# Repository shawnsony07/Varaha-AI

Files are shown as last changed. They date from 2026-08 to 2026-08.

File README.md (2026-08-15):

# Varaha AI: Autonomous Wild Boar Deterrent & Long-Range Telemetry Swarm 🐗📡

<p align="center">
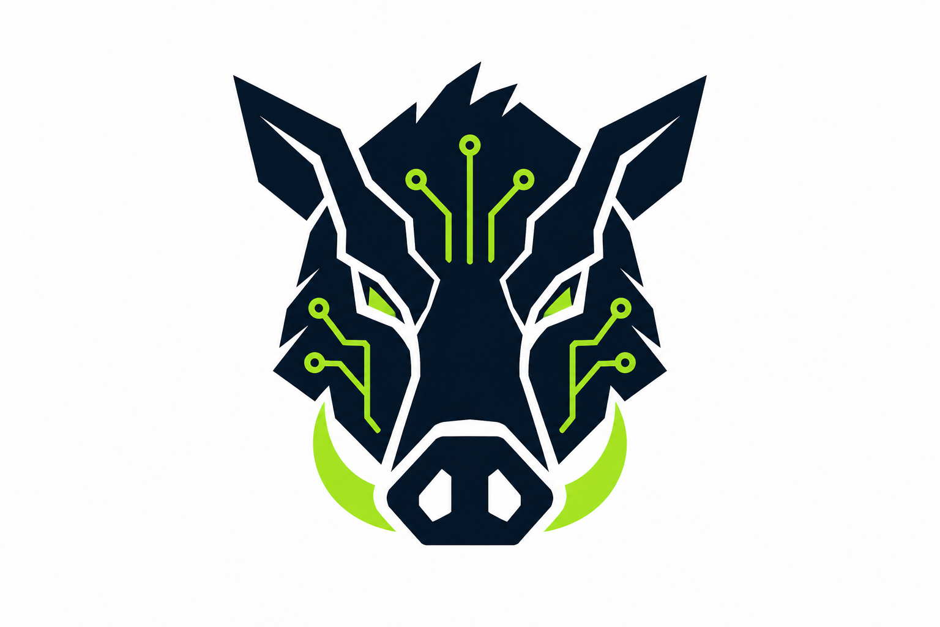
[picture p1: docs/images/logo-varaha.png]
Varaha AI Logo
  
</p>






**Repository Link:** https://github.com/shawnsony07/Varaha-AI

**Demonstration Video:** [Watch on YouTube](https://youtu.be/mFBCUHmKaQ8) 
> [!NOTE]
> The frequency has been shifted into the audible range for this demo so you can hear it working!
---

## 📖 Table of Contents
1. [Project Overview](#-project-overview)
2. [Inspiration & Problem Statement](#-inspiration--problem-statement)
3. [Functionality & Output](#-functionality--output)
4. [The Optimization Journey (Arm-Specific Acceleration)](#-the-optimization-journey-arm-specific-acceleration)
5. [Hardware Architecture](#%EF%B8%8F-hardware-architecture)
6. [Repository Structure](#-repository-structure)
7. [Setup Instructions](#-setup-instructions)
8. [License](#-license)

---

## 💡 Project Overview

**Varaha AI** is an intelligent, dual-node agricultural protection system combining on-device Swift-YOLO vision models, 35 kHz analog ultrasonic deterrence, and P2P LoRa telemetry.

**Why 35 kHz Ultrasonic Deterrence?**
While human hearing typically tops out around 20 kHz, wild boars possess a significantly higher auditory range. When the vision model detects a threat, it triggers a targeted 35 kHz ultrasonic sweep. This causes acute auditory discomfort that drives the boars away from crops, while remaining completely silent and harmless to farmers and local residents.

> [!IMPORTANT]
> **🏆 Why Varaha AI should win:**
> Most existing wildlife deterrent solutions are blunt instruments — electric fences that shock anyone who touches them, poison bait that enters the food chain, or loud acoustic sirens that disturb entire communities through the night. Varaha AI is fundamentally different: it is a **targeted, non-lethal, and human-safe** solution. The 35 kHz ultrasonic deterrent is completely inaudible to humans, causes no harm to livestock or birdlife, and leaves zero environmental footprint. It only activates when the Arm-accelerated vision model confirms a boar is present — not a farmer, not an animal, not a false alarm.
>
> Beyond its ethical design, Varaha AI is not a software-only optimization — it is a complete, field-deployable AI system that closes the loop from raw pixel inference to physical deterrence hardware. We achieved **100% NPU offload** on the Arm Ethos-U55 with **zero CPU fallbacks**, running a production Swift-YOLO model in just **198 KiB of SRAM** — an extreme memory constraint that required the full Arm Vela compilation pipeline. This tight integration of Arm-accelerated TinyML inference with custom analog electronics, off-grid LoRa telemetry, and a 3D-printed weatherproof enclosure demonstrates what Arm-powered edge AI can do in the real world: protect livelihoods, eliminate cloud dependency, and run indefinitely on a battery in a field.

<p align="center">
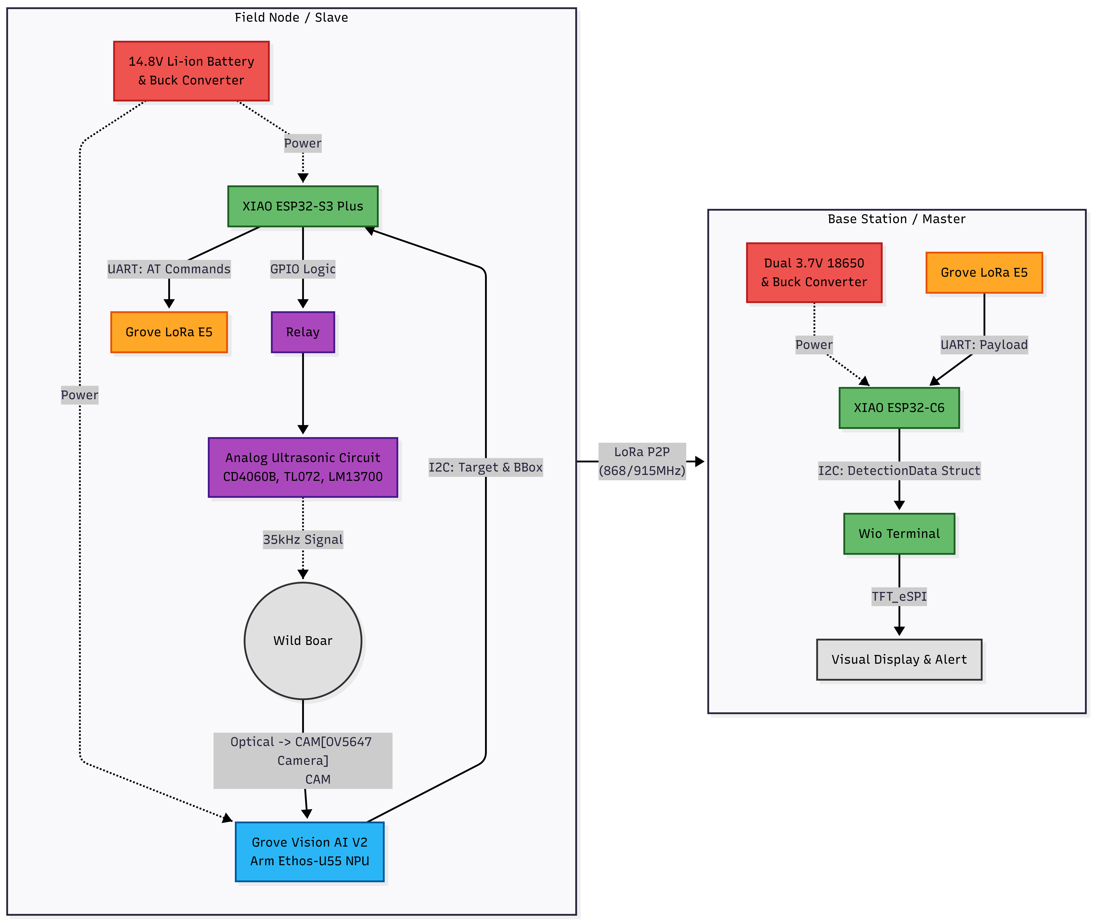
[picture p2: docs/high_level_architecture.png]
High Level Architecture
  
  <br><i>Figure 1: High Level Architecture of the Varaha AI System</i>
</p>

---

## 🌍 Inspiration & Problem Statement

Human-wildlife conflict—specifically destructive foraging by wild boars—causes severe agricultural losses for farming communities worldwide, with the crisis reaching a breaking point in Kerala, India. Kerala's wild boar population grew by more than **40%** over 15 years, reaching approximately 58,000 in 2019. These highly adaptable animals breed quickly and feed indiscriminately, heavily damaging essential local crops like tapioca, sweet potatoes, and plantains.

Beyond economic devastation—where some farmers report daily losses up to **Rs 150** and suffer through a broken compensation system—the boars pose a severe physical threat. Wild boars are responsible for sudden, unprovoked attacks and human fatalities occurring entirely outside of forested areas. Traditional solutions like electric fencing are expensive to install and maintain across vast acreage, while manual patrols are hazardous and unsustainable.

Varaha AI was engineered to solve this crisis by providing a completely autonomous, field-deployable shield. By coupling hardware-accelerated computer vision at the far edge with targeted ultrasonic harassment and long-range radio alerts, farmers get real-time crop protection without relying on cellular infrastructure or cloud connectivity.

---

## ⚡ Functionality & Output

Varaha AI operates as a fully autonomous detection-to-deterrence pipeline. Here is the complete end-to-end flow triggered by a single boar detection event:

```mermaid
flowchart TD
    classDef camera    fill:#FFD700,stroke:#333,stroke-width:2px,color:#000
    classDef npu       fill:#00C853,stroke:#333,stroke-width:2px,color:#000
    classDef model     fill:#69F0AE,stroke:#333,stroke-width:2px,color:#000
    classDef logic     fill:#40C4FF,stroke:#333,stroke-width:2px,color:#000
    classDef deterrent fill:#FF6D00,stroke:#333,stroke-width:2px,color:#000
    classDef lora      fill:#E040FB,stroke:#333,stroke-width:2px,color:#000
    classDef base      fill:#FF4081,stroke:#333,stroke-width:2px,color:#000
    classDef display   fill:#18FFFF,stroke:#333,stroke-width:2px,color:#000

    CAM["📷 OV5647 Camera\nField Node"]:::camera
    VIS["🧠 Grove Vision AI V2\nWiseEye2 HX6538\nArm Cortex-M55 + Ethos-U55 NPU"]:::npu
    MDL["⚡ Swift-YOLO INT8\nmodel_vela.tflite\n100% NPU Offload\nBounding Box + Confidence Score"]:::model
    S3["🎛️ XIAO ESP32-S3 Plus\nLogic Controller"]:::logic
    DET["🔊 Analog Ultrasonic Circuit\n35 kHz Sweep\nCD4060B -> TL072 -> LM13700\n-> MOSFET -> Piezo Transducer"]:::deterrent
    LORA["📡 Grove Wio-E5\nLoRa P2P | 866 MHz\nSF12 | BW125 | 14 dBm"]:::lora
    C6["📻 XIAO ESP32-C6\nBase Station\nDecodes: Flag | RSSI | SNR"]:::base
    WIO["🖥️ Wio Terminal\nTFT UI Dashboard\nLive Alerts · Signal Strength · Network Status"]:::display

    CAM -->|"Video Feed"| VIS
    VIS -->|"Runs inference"| MDL
    MDL -->|"I2C — Detection Result"| S3
    S3 -->|"Triggers 14.8V Relay"| DET
    S3 -->|"UART — LoRa Packet"| LORA
    LORA -->|"P2P Radio | up to several km"| C6
    C6 -->|"I2C"| WIO
```

**Final Output:** A boar is detected, silently repelled via targeted 35 kHz ultrasound (inaudible and harmless to humans), and the farmer receives an instant visual alert on a dashboard up to several kilometres away — all with zero cloud connectivity and zero CPU fallbacks on the Arm Ethos-U55 NPU.

---

## 🚀 The Optimization Journey (Arm-Specific Acceleration)

To meet the rigorous latency, memory, and power constraints of edge deployment, we conducted a three-tier model optimization process. Our goal was to maximize **Arm-specific optimization**, **model compactness**, and **inference speed** for the Grove Vision AI V2 (Arm Cortex-M55 + Ethos-U55).

<p align="center">
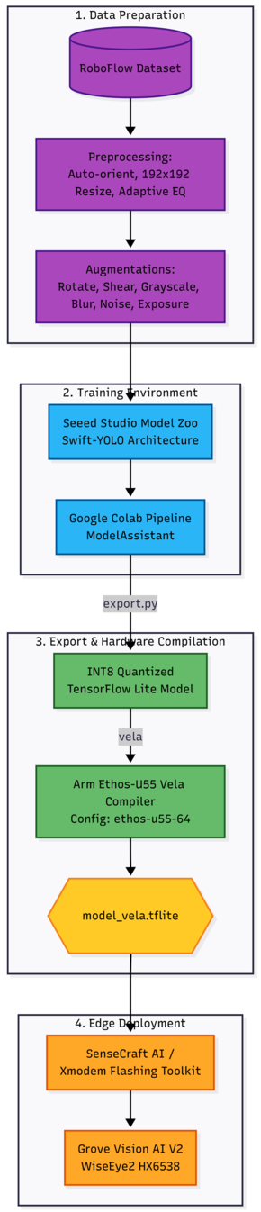
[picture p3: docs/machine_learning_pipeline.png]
Machine Learning Pipeline
  
  <br><i>Figure 2: Three-tier Machine Learning Optimization Pipeline</i>
</p>

### 📊 Comprehensive 3-Model Benchmark Comparison

| Metric / Parameter | Model 1: Edge Impulse FOMO | Model 2: Edge Impulse YOLO | Model 3: Swift-YOLO (SSCMA — Production) |
| :--- | :--- | :--- | :--- |
| **Pipeline / Framework** | Edge Impulse | Edge Impulse | Google Colab / SSCMA (ModelAssistant) |
| **Detection Task Type** | Centroid / Point Detection | Bounding Box Detection | Bounding Box Detection |
| **Input Resolution** | 96 × 96 | 160 × 160 | **192 × 192** |
| **Quantization Precision** | INT8 | INT8 | **INT8** |
| **Model Size on Disk/Flash** | **30.00 KiB** | **608.00 KiB** | **1024.70 KiB (1.00 MB)** |
| **mAP@50 (IoU=0.50)** | N/A *(Centroid Model)* | 77.4% | **70.2%** |
| **mAP@50:95 (Overall mAP)** | N/A *(Centroid Model)* | 41.9% | **37.7%** |
| **Precision** | 45.3% | ~51.6% | **68.4%** |
| **Recall (Overall)** | 14.1% | 49.4% | **54.9%** |
| **F1-Score** | 21.5% | ~50.5% | **60.9%** |
| **NPU Offload Rate** | Unverified (Partial CPU) | Unverified (Partial CPU) | **100.0% (175 / 175 Operators)** |
| **CPU Fallback Rate** | High | Moderate | **0.0% (0 Operators)** |
| **SRAM Footprint** | Unknown | Unknown | **198.00 KiB** |
| **Compute Workload** | ~30 M MACs | ~90 M MACs | **123.6 M MACs / inference** |
| **Target Arm Hardware** | Arm Ethos-U55 / Cortex-M55 | Arm Ethos-U55 / Cortex-M55 | **Arm Ethos-U55 NPU (500 MHz, 64 MACs/cycle)** |

---

### Model 1: Edge Impulse FOMO (The Baseline Prototype)
We initially tested a Faster Objects, More Objects (FOMO) centroid-detection architecture for its extreme speed.

| Parameter | Value |
| :--- | :--- |
| Architecture | FOMO (Centroid Detection) |
| Precision | 45.3% |
| Recall | 14.1% |
| F1-Score | 21.5% |
| Bounding Box Output | ❌ No |
| NPU Optimized | ❌ No |

> **Conclusion:** FOMO failed to capture the spatial context and varied postures of wild boars in dynamic outdoor environments. The critically low recall made it unviable for field protection.

---

### Model 2: Edge Impulse YOLO (The Accuracy Benchmark)
We escalated to a standard Bounding Box YOLO model to establish a target accuracy ceiling.

| Parameter | Value |
| :--- | :--- |
| Architecture | Bounding Box YOLO |
| mAP@50 | 77.4% |
| Overall mAP | 41.9% |
| Recall | 49.4% |
| Bounding Box Output | ✅ Yes |
| NPU Optimized | ❌ Partial (CPU fallbacks) |

> **Conclusion:** While highly accurate, standard YOLO ops frequently result in partial CPU fallbacks when deployed to micro-NPUs, creating latency bottlenecks and increased power draw.

---

### Model 3: Swift-YOLO via SSCMA (The Final Optimized Build) ✅
Our final iteration utilized a custom **Swift-YOLO** architecture trained via Seeed Studio ModelAssistant (SSCMA), INT8-quantized and compiled for the **Arm Ethos-U55 NPU** using the Vela toolchain.

| Parameter | Value |
| :--- | :--- |
| Architecture | Swift-YOLO (INT8 Quantized) |
| Training Framework | SSCMA (Seeed Studio ModelAssistant) |
| Compiler | Arm Vela |
| Target Hardware | Grove Vision AI V2 (WiseEye2 HX6538) |
| Target NPU | Arm Ethos-U55 |
| mAP@50 | **70.2%** |
| Recall | **54.9%** |
| SRAM Footprint | **198.00 KiB** |
| Off-Chip Flash Footprint | **1024.70 KiB** |
| Compute Workload | **123.6 M MACs / inference** |
| Total Operators | 175 |
| NPU Offload Rate | **100.0% (175 / 175 operators)** |
| CPU Fallback Rate | **0.0% (0 operators)** |
| Quantization | INT8 |
| Vela Compiled | ✅ Yes |

**The Optimization Victory:** We successfully traded a marginal 7.2% drop in mAP@50 to achieve a **100% Arm NPU execution rate**. By eliminating all CPU fallbacks and shrinking the active memory footprint to under 200 KiB of SRAM, Varaha AI achieves maximum FPS and drastically lower power consumption for continuous battery-operated field deployment.

<p align="center">
  Swift-YOLO Wild Boar Detection
  <br><i>Figure 3: On-device bounding box detection via Swift-YOLO</i>
</p>

---

## ⚙️ Hardware Architecture

Varaha AI operates on a seamless dual-node architecture.

<p align="center">
  Varaha AI Final Hardware Setup
  <br><i>Figure 4: The fully assembled Varaha AI Field Node and Base Station</i>
</p>

### 1. Field Node (Slave)
The Field Node acts as the silent watcher. An OV5647 camera feeds live video into the **Grove Vision AI V2**. A **XIAO ESP32-S3 Plus** acts as the logic controller, querying the vision module via I2C and transmitting LoRa packets via UART to a **Grove Wio-E5** (AT test mode, raw P2P — not LoRaWAN).

**LoRa RF Configuration (TX):**

| Parameter | Value |
| :--- | :--- |
| Frequency | **866 MHz** |
| Spreading Factor | **SF12** |
| Bandwidth | **125 kHz** |
| TX Power | **14 dBm** |
| Preamble Length | 12 |
| Protocol | Raw P2P Packet (`AT+TEST=TXLRPKT`) |
| Payload | Detection flag (`SEEED` + `01`/`00`) |

<p align="center">
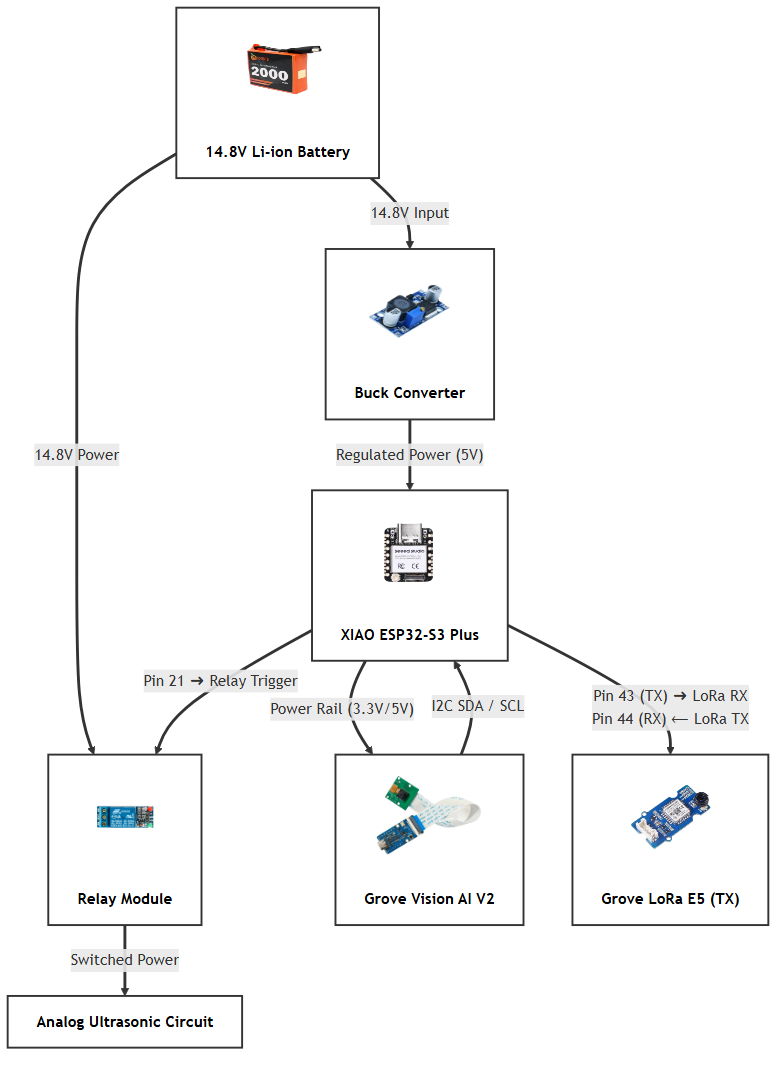
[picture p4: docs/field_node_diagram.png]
Field Node Wiring Diagram
  
  <br><i>Figure 5: Field Node (Slave) Wiring Diagram</i>
</p>

#### ⚡ Custom Analog Ultrasonic Deterrent Circuit
When a boar is detected, the S3 triggers a 14.8V relay. This powers a custom-engineered analog circuit featuring a **4.48 MHz crystal oscillator** and **CD4060B** binary counter/divider to generate a precise base frequency. The signal is buffered via a **TL072 op-amp**, shaped by an **LM13700 OTA**, and driven through a power MOSFET and 100 µH boost inductor into a piezoelectric transducer, blasting a 35 kHz sweep.

| Schematic Blueprint | Physical Prototype |
| :---: | :---: |
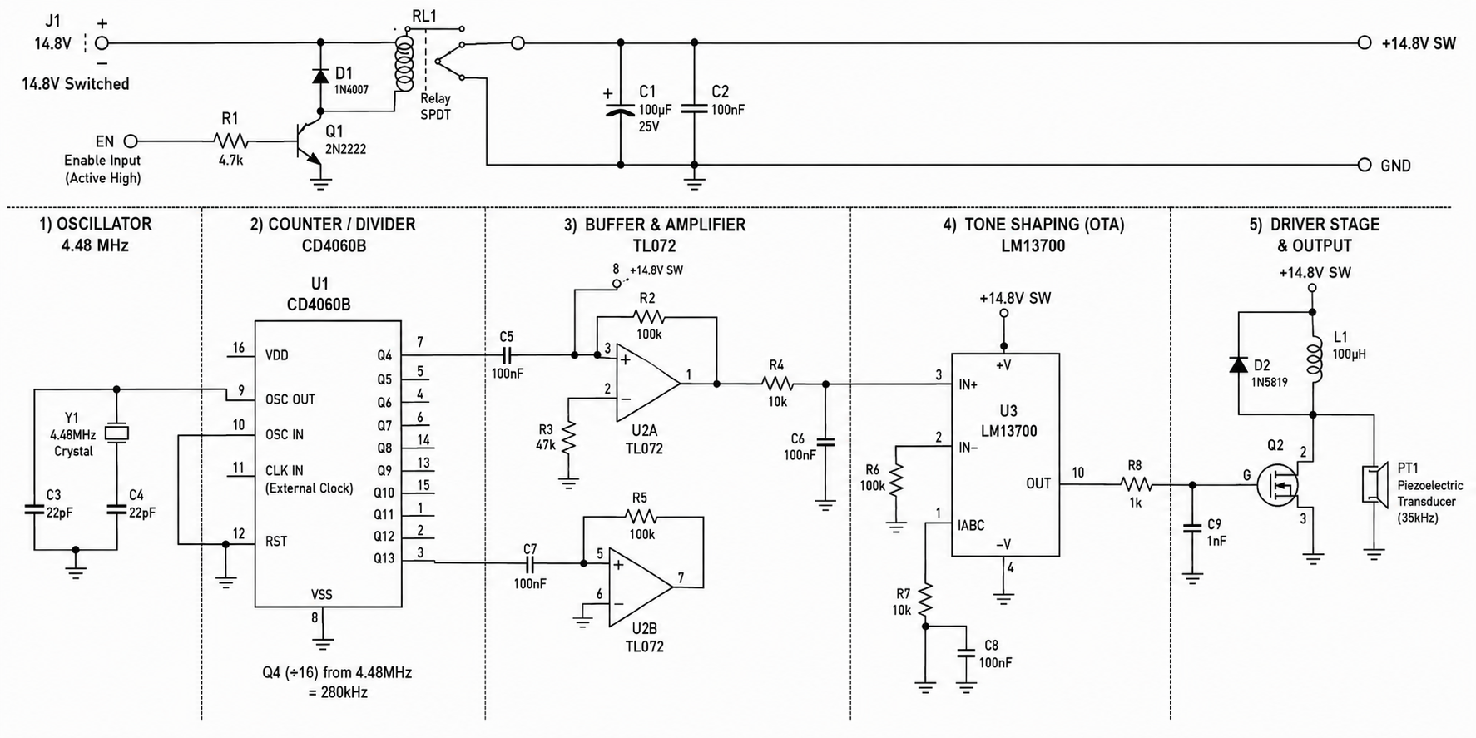
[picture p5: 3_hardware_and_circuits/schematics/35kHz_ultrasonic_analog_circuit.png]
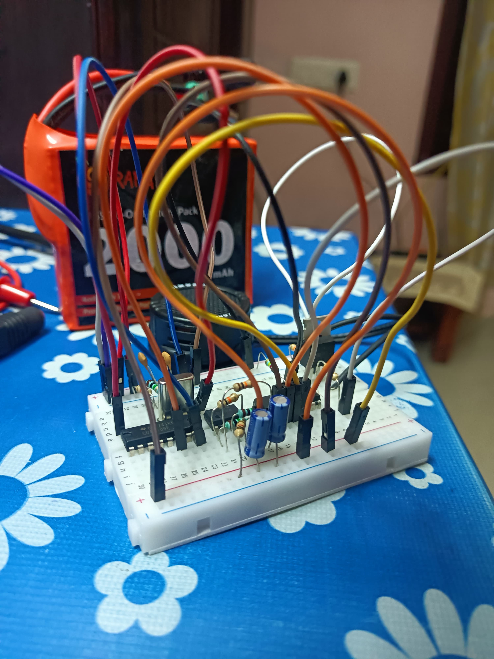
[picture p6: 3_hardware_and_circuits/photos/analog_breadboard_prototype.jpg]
|  |  |

#### 🛡️ Weather-Resistant 3D Enclosure
The node is housed in a custom-designed, 3D-printable enclosure (`HogWatch_Case_v2.stl`) featuring a recessed optical viewport, passive ventilation grids for the power step-down (buck converter), an acoustic port for the ultrasonic transducer, and a precise top slit that allows the lid to seamlessly slide in and out for easy internal access.

<p align="center">
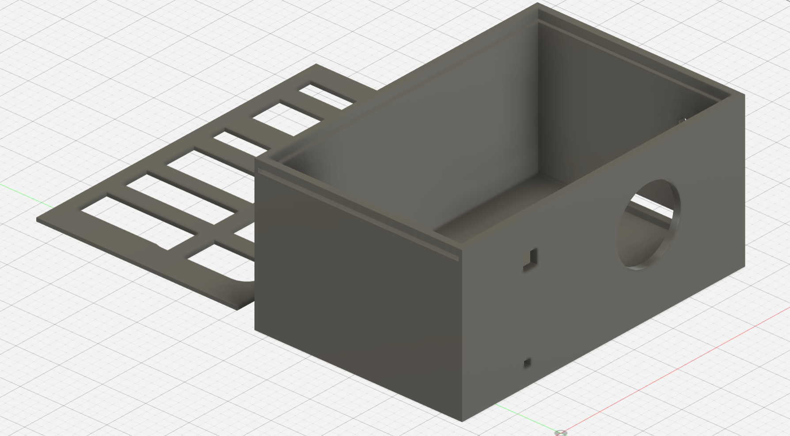
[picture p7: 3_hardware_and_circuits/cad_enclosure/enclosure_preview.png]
  
  <br><i>Figure 6: 3D-printable Weather-Resistant Enclosure</i>
</p>

### 2. Base Station (Master)
Located at the farmhouse, a **XIAO ESP32-C6** listens for P2P radio transmissions on **866 MHz** using a second Wio-E5 configured identically (`AT+TEST=RFCFG,866,SF12,125,12,15,14`). On packet reception, it decodes the telemetry (Detection Flag, RSSI, SNR) and pushes it via I2C to a **Wio Terminal**, rendering a color TFT UI Dashboard with live alerts and network diagnostics.

<p align="center">
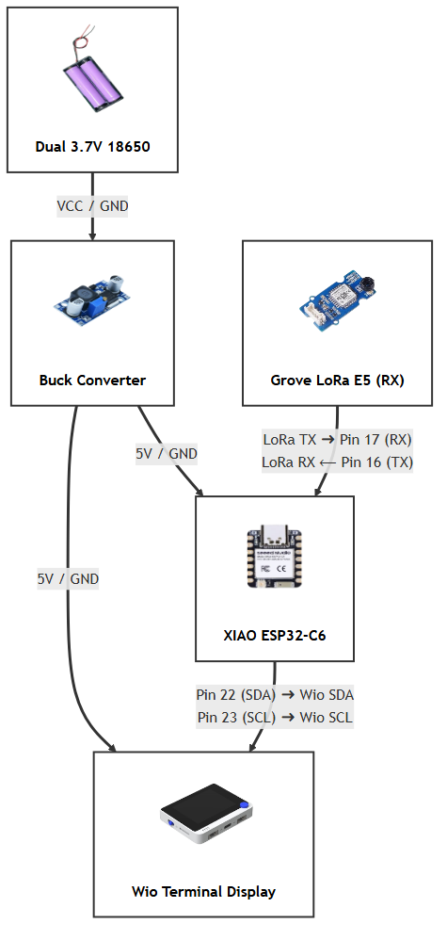
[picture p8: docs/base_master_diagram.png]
Base Master Diagram
  
  <br><i>Figure 7: Base Station (Master) Wiring Diagram</i>
</p>

---

## 📂 Repository Structure

```text
Varaha-AI/
├── 1_machine_learning_pipeline/         # Model evaluation and training progression
│   ├── model_1_edge_impulse_fomo/       # Tier 1: Initial Centroid Detection Prototype
│   ├── model_2_edge_impulse_yolo/       # Tier 2: Standard Bounding Box Model
│   └── model_3_swift_yolo_sscma/        # Tier 3: Production Hardware-Optimized Model
│       ├── notebooks/                   # Swift-YOLO Colab training pipeline
│       └── compiled_artifacts/          # INT8 Vela compiled binaries (model_vela.tflite)
│
├── 2_edge_node_firmware/                # Embedded C++ codebase
│   ├── field_slave_node_s3/             # XIAO ESP32-S3 + Vision AI + LoRa TX + Relay
│   ├── base_master_node_c6/             # XIAO ESP32-C6 + LoRa RX
│   └── wio_terminal_display/            # Wio Terminal I2C Slave + TFT UI Dashboard
│
├── 3_hardware_and_circuits/             # Schematics, prototypes, and CAD
│   ├── cad_enclosure/                   # 3D printable STL files
│   ├── photos/                          # Prototype implementation photos
│   └── schematics/                      # Analog circuit & power distribution diagrams
│
├── tools/xmodem_flasher/                # Python scripts for flashing Grove Vision AI V2
└── docs/                                # Visual assets for architecture & wiring
```

---

## 🛠️ Setup Instructions

### Prerequisites — Arduino Libraries
Install the following libraries via the Arduino IDE Library Manager before compiling:

| Library | Board Target |
| :--- | :--- |
| `Seeed Arduino SSCMA` | XIAO ESP32-S3 (Vision AI I2C) |
| `Seeed_Arduino_LoRaWan` | XIAO ESP32-S3 & C6 (Wio-E5 UART) |
| `Seeed Arduino rpcWiFi` | Wio Terminal |
| `Seeed Arduino FS` | Wio Terminal |
| `Seeed Arduino SFUD` | Wio Terminal |
| `TFT_eSPI` | Wio Terminal (TFT Display) |

Board package URLs to add in Arduino IDE → Preferences:
`https://files.seeedstudio.com/arduino/package_seeeduino_boards_index.json`

---

### 1. Build and Flash the ESP32 & Wio Terminal Nodes
1. Wire your hardware components according to the Pictorial Wiring Diagrams (Figures 3 and 5).
2. Open the Arduino IDE.
3. Navigate to `2_edge_node_firmware/` and open the respective `.ino` files.
4. Select your target boards from the Boards Manager:

| File | Target Board |
| :--- | :--- |
| `field_slave_node_s3/HogWatch-lora-vision.ino` | XIAO ESP32-S3 |
| `base_master_node_c6/HogWatch_esp32_c6_wio_terminal.ino` | XIAO ESP32-C6 |
| `wio_terminal_display/HogWatch_wio_terminal.ino` | Seeed Wio Terminal |

5. Compile and upload the code to each respective microcontroller.

---

### 2. Deploy the Optimized Model to the Arm Ethos-U55
The highly-optimized NPU model must be flashed to the Grove Vision AI V2 (WiseEye2 HX6538) via the XMODEM protocol using the provided Python toolset.

1. Connect the Grove Vision AI V2 to your computer via USB-C.
2. Install the flashing dependencies:
```bash
pip install -r tools/xmodem_flasher/requirements.txt
```

3. Run the XMODEM flashing script to deploy the `model_vela.tflite` payload:

```bash
python3 tools/xmodem_flasher/xmodem_send.py --port=COM_PORT --baudrate=921600 --protocol=xmodem --file=firmware.img --model="1_machine_learning_pipeline/model_3_swift_yolo_sscma/compiled_artifacts/model_vela.tflite 0x200000 0x00000"
```

*(Replace `COM_PORT` with your Serial Port, e.g., `COM3` on Windows or `/dev/ttyUSB0` on Linux/macOS)*

---

### 3. Run & Validate on the Physical Arm-Powered Device

Once the model is flashed to the Grove Vision AI V2, you can validate the NPU inference and the full hardware pipeline:

1. **Power the System:** Power on the Base Station (XIAO ESP32-C6) and the Field Node (Grove Vision AI V2 + XIAO ESP32-S3).
2. **Monitor the Edge Node:** Connect the Field Node's XIAO ESP32-S3 to your computer and open a Serial Monitor at `115200` baud.
3. **Trigger a Detection:** Point the Grove Vision AI V2 camera at a wild boar (or a monitor displaying an image/video of a wild boar).
4. **Validate NPU Output:** In the Serial Monitor, confirm the I2C payload transfer from the Arm Cortex-M55/Ethos-U55:
```text
Vision: Wild boar detected! Score=82, Box=[x,y,w,h]
LoRa TX: Wild boar DETECTED
```

5. **Validate Hardware Deterrent:** Listen for the physical "click" of the 14.8V relay activating the analog ultrasonic deterrent circuit.
6. **Validate LoRa Telemetry:** Look at the Wio Terminal screen. The UI will instantly shift from a green **"FIELD CLEAR"** status to a flashing red **"BOAR DETECTED!"** alert.

---

### 4. Validate Inference via Arm Virtual Hardware (AVH) / CLI

To validate that the Vela-compiled model runs correctly on an Arm Cortex-M55 + Ethos-U55 target *without* physical hardware, use the Ethos-U NPU driver simulator:

```bash
# Install Arm's ethos-u-vela toolchain
pip install ethos-u-vela

# Inspect operator offload summary of the compiled model
vela 1_machine_learning_pipeline/model_3_swift_yolo_sscma/compiled_artifacts/model_vela.tflite \
     --accelerator-config=ethos-u55-64 \
     --system-config=Ethos_U55_High_End_Embedded \
     --output-dir=./vela_validation_output

# Review output — confirm 175/175 operators on NPU, 0 on CPU
cat vela_validation_output/epoch_100_int8_summary_Ethos_U55_High_End_Embedded.csv
```

---

## 📜 License
This project is open-source and released under the MIT License. See the [LICENSE](LICENSE) file for complete details.

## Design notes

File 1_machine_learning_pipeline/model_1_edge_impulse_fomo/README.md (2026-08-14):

# Model 1 — Edge Impulse FOMO (Tier 1 Baseline)

## Architecture
Faster Objects More Objects (FOMO) — a lightweight centroid-detection model designed for microcontrollers. Trained via Edge Impulse on the Varaha hog dataset.

## Purpose
Initial prototype to validate the feasibility of on-device pig detection. FOMO outputs object centroids rather than bounding boxes, making it extremely fast but less precise.

## Key Results
See model.4_fomo_8.json for evaluation metrics and confusion matrix output.

## Limitations
- No bounding box output (centroid only)
- Lower precision in cluttered outdoor scenes
- Superseded by Edge Impulse YOLO (Tier 2)

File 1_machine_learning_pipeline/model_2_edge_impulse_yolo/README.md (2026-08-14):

# Model 2 — Edge Impulse YOLO (Tier 2 Baseline)

## Architecture
Standard bounding-box YOLO model trained via Edge Impulse on the Varaha hog dataset.

## Purpose
Upgrade from FOMO to full bounding-box detection. Validated strong mAP before moving to hardware-optimized Swift-YOLO.

## Key Results
See model.4_yolo.json for COCO evaluation metrics.
- **mAP@50: 77.4%**

## Limitations
- Not optimized for Arm Ethos-U55 NPU
- Larger model footprint vs Swift-YOLO
- Superseded by Swift-YOLO SSCMA (Tier 3)

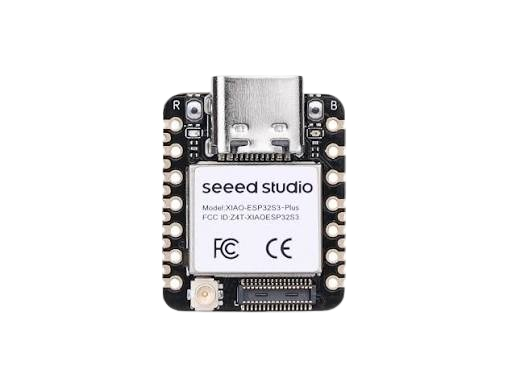
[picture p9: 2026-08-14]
docs/images/XIAO_ESP32-S3_Plus.png

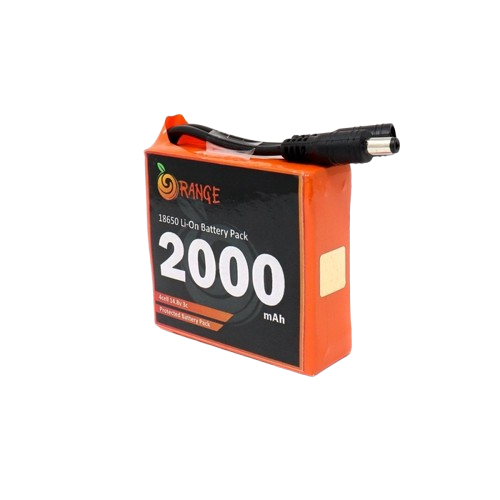
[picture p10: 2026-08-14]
docs/images/14.8V_Li-ion_Battery.png

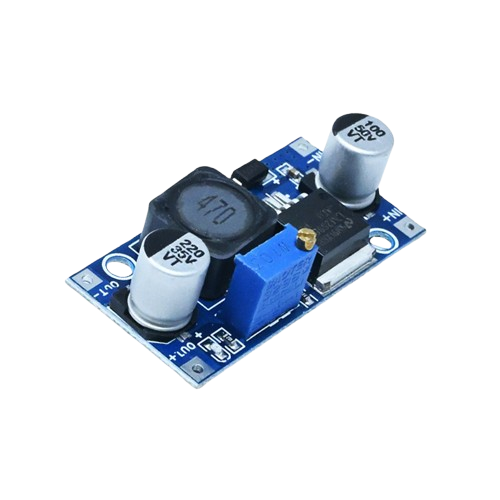
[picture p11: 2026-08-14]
docs/images/Buck_Converter.png

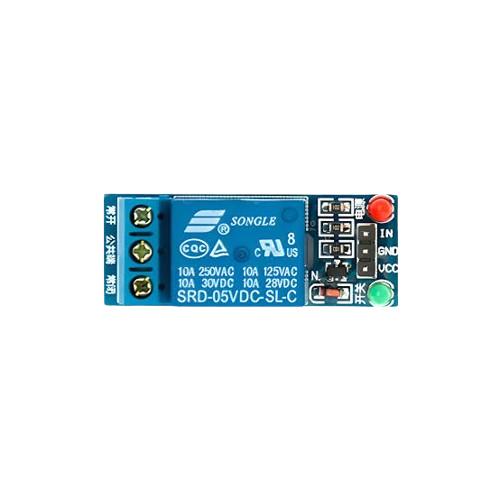
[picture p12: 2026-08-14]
docs/images/Relay_Module.png

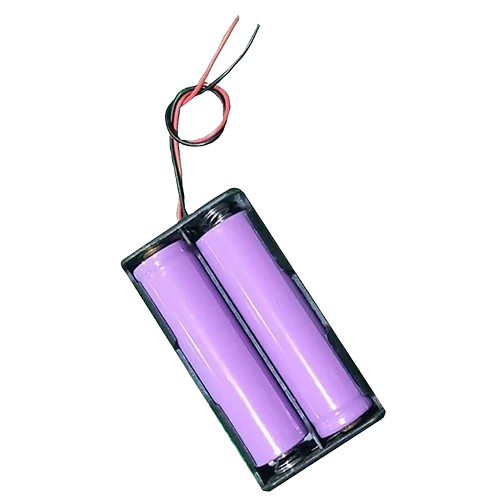
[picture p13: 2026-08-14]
docs/images/Dual_3.7V_18650_Batteries.png

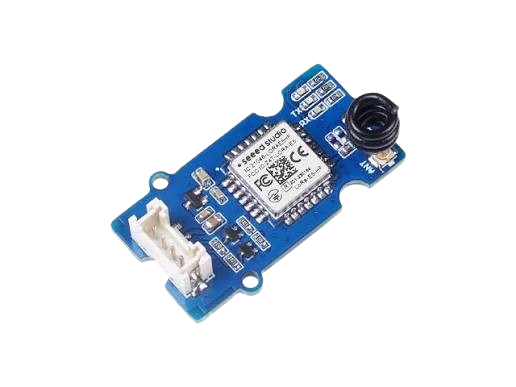
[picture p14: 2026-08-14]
docs/images/Grove_LoRa_E5.png

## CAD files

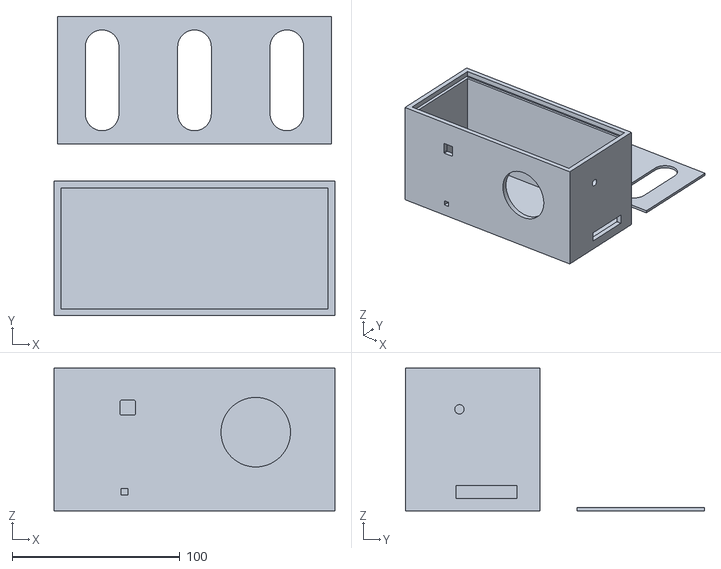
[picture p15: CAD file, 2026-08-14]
3_hardware_and_circuits/cad_enclosure/HogWatch_Case_v2.stl
167.0 x 178.0 x 85.0

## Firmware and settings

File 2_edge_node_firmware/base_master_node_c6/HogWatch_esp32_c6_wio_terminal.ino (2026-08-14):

#include <Arduino.h>
#include <Wire.h>

// Pin definitions for XIAO ESP32-C6/S3
#define TX_PIN 16  // D6 - Connect to Wio-E5 RX
#define RX_PIN 17  // D7 - Connect to Wio-E5 TX

// I2C Configuration
#define I2C_SDA_PIN 22  // D4 - Connect to Wio Terminal SDA
#define I2C_SCL_PIN 23  // D5 - Connect to Wio Terminal SCL
#define WIO_TERMINAL_I2C_ADDR 0x42

// Master node configuration
static char recv_buf[512];
static bool is_exist = false;
static unsigned long lastHeartbeat = 0;
static unsigned long lastDetectionTime = 0;
static int consecutiveFailures = 0;
static int totalDetections = 0;
static bool currentFieldStatus = true; // true = clear, false = boar detected
static int currentRSSI = 0;
static int currentSNR = 0;

// I2C Data Structure
struct DetectionData {
    uint8_t fieldClear;        // 1 = clear, 0 = boar detected
    uint8_t totalDetections;   // Total detections count
    int8_t rssi;              // RSSI value
    int8_t snr;               // SNR value
    uint8_t commFailures;     // Communication failure count
    uint32_t lastDetectionTime; // Time since last detection (seconds)
    uint32_t systemUptime;    // System uptime (seconds)
    uint8_t loraConnected;    // 1 = connected, 0 = disconnected
};

static int at_send_check_response(char *p_ack, int timeout_ms, char*p_cmd, ...)
{
    int ch = 0;
    int index = 0;
    int startMillis = 0;
    va_list args;
    memset(recv_buf, 0, sizeof(recv_buf));
    va_start(args, p_cmd);
    Serial1.printf(p_cmd, args);
    va_end(args);
    delay(200);
    startMillis = millis();

    if (p_ack == NULL)
    {
        return 0;
    }

    do
    {
        while (Serial1.available() > 0)
        {
            ch = Serial1.read();
            recv_buf[index++] = ch;
            delay(2);
        }

        if (strstr(recv_buf, p_ack) != NULL)
        {
            return 1;
        }

    } while (millis() - startMillis < timeout_ms);
    return 0;
}

static int recv_parse_detection(void)
{
    char ch;
    int index = 0;
    memset(recv_buf, 0, sizeof(recv_buf));
    while (Serial1.available() > 0)
    {
        ch = Serial1.read();
        recv_buf[index++] = ch;
        delay(2);
    }

    if (index)
    {
        char *p_start = NULL;
        char data[32] = {0};
        int rssi = 0;
        int snr = 0;

        p_start = strstr(recv_buf, "+TEST: RX \"5345454544");
        if (p_start)
        {
            p_start = strstr(recv_buf, "5345454544");
            if (p_start && (1 == sscanf(p_start, "5345454544%s", data)))
            {
                data[4] = 0;
                
                // Parse detection status
                int detection_status = (int)strtol(data, NULL, 16);
                
                // Get signal quality
                p_start = strstr(recv_buf, "RSSI:");
                if (p_start && (1 == sscanf(p_start, "RSSI:%d,", &rssi)))
                {
                    currentRSSI = rssi;
                }
                
                p_start = strstr(recv_buf, "SNR:");
                if (p_start && (1 == sscanf(p_start, "SNR:%d", &snr)))
                {
                    currentSNR = snr;
                }

                // Update status
                if (detection_status == 1)
                {
                    currentFieldStatus = false; // Boar detected
                    totalDetections++;
                    lastDetectionTime = millis();
                    Serial.print("🐗 WILD BOAR DETECTED! ");
                }
                else
                {
                    currentFieldStatus = true; // Field clear
                    Serial.print("✅ Area Clear ");
                }

                // Print meaningful information
                Serial.print("[");
                Serial.print(millis()/1000);
                Serial.print("s] ");
                Serial.print("| Signal: RSSI=");
                Serial.print(rssi);
                Serial.print("dBm, SNR=");
                Serial.print(snr);
                Serial.println("dB");
                
                consecutiveFailures = 0; // Reset failure counter on successful reception
                
                // Send data to Wio Terminal via I2C
                sendDataToWioTerminal();
                
                return 1;
            }
        }
    }
    return 0;
}

static int node_recv(uint32_t timeout_ms)
{
    at_send_check_response("+TEST: RXLRPKT", 1000, "AT+TEST=RXLRPKT\r\n");
    int startMillis = millis();
    do
    {
        if (recv_parse_detection())
        {
            return 1;
        }
    } while (millis() - startMillis < timeout_ms);
    return 0;
}

void sendDataToWioTerminal()
{
    DetectionData data;
    
    // Prepare data structure
    data.fieldClear = currentFieldStatus ? 1 : 0;
    data.totalDetections = min(totalDetections, 255); // Limit to uint8_t range
    data.rssi = constrain(currentRSSI, -128, 127);
    data.snr = constrain(currentSNR, -128, 127);
    data.commFailures = min(consecutiveFailures, 255);
    data.lastDetectionTime = lastDetectionTime > 0 ? (millis() - lastDetectionTime) / 1000 : 0;
    data.systemUptime = millis() / 1000;
    data.loraConnected = is_exist ? 1 : 0;
    
    // Send data via I2C
    Wire.beginTransmission(WIO_TERMINAL_I2C_ADDR);
    Wire.write((uint8_t*)&data, sizeof(DetectionData));
    int result = Wire.endTransmission();
    
    if (result != 0) {
        Serial.print("I2C transmission error: ");
        Serial.println(result);
    } else {
        Serial.println("📱 Data sent to Wio Terminal");
    }
}

static void print_status_summary()
{
    unsigned long currentTime = millis();
    Serial.println("\n=== WILD BOAR MONITORING STATUS ===");
    Serial.print("System Uptime: ");
    Serial.print(currentTime / 1000);
    Serial.println(" seconds");
    
    Serial.print("Total Detections: ");
    Serial.println(totalDetections);
    
    if (lastDetectionTime > 0)
    {
        Serial.print("Last Detection: ");
        Serial.print((currentTime - lastDetectionTime) / 1000);
        Serial.println(" seconds ago");
    }
    else
    {
        Serial.println("Last Detection: None since startup");
    }
    
    Serial.print("Current Status: ");
    Serial.println(currentFieldStatus ? "Field Clear ✅" : "Boar Detected 🐗");
    
    if (consecutiveFailures > 0)
    {
        Serial.print("⚠️ Communication Issues: ");
        Serial.print(consecutiveFailures);
        Serial.println(" consecutive failures");
    }
    else
    {
        Serial.println("📡 Communication: OK");
    }
    Serial.println("====================================\n");
    
    // Send periodic update to Wio Terminal
    sendDataToWioTerminal();
}

void setup(void)
{
    Serial.begin(115200);
    Serial1.begin(9600, SERIAL_8N1, RX_PIN, TX_PIN);
    
    // Initialize I2C as master
    Wire.begin(I2C_SDA_PIN, I2C_SCL_PIN);
    Wire.setClock(100000); // 100kHz
    
    Serial.println("=== Wild Boar Detection Master Station ===");
    Serial.println("Initializing I2C communication...");
    Serial.print("I2C SDA: Pin ");
    Serial.print(I2C_SDA_PIN);
    Serial.print(", SCL: Pin ");
    Serial.println(I2C_SCL_PIN);
    Serial.print("Wio Terminal I2C Address: 0x");
    Serial.println(WIO_TERMINAL_I2C_ADDR, HEX);
    
    Serial.println("Connecting to LoRa module...");
    
    // Initialize LoRa module
    if (at_send_check_response("+AT: OK", 1000, "AT\r\n"))
    {
        is_exist = true;
        Serial.println("✅ LoRa module connected successfully!");
        
        // Configure LoRa parameters
        at_send_check_response("+MODE: TEST", 1000, "AT+MODE=TEST\r\n");
        at_send_check_response("+TEST: RFCFG", 1000, "AT+TEST=RFCFG,866,SF12,125,12,15,14,ON,OFF,OFF\r\n");
        delay(200);
        
        Serial.println("📡 LoRa parameters configured");
        Serial.println("🔍 Starting wild boar monitoring...\n");
    }
    else
    {
        is_exist = false;
        Serial.println("❌ LoRa module not found!");
    }
    
    lastHeartbeat = millis();
    
    // Send initial data to Wio Terminal
    sendDataToWioTerminal();
}

void loop(void)
{
    if (is_exist)
    {
        // Listen for detection messages with longer timeout for better reliability
        if (!node_recv(5000))  // Increased from 3000 to 5000ms
        {
            consecutiveFailures++;
            Serial.print("[");
            Serial.print(millis()/1000);
            Serial.print("s] ");
            Serial.print("📶 No signal from field sensor (timeout #");
            Serial.print(consecutiveFailures);
            Serial.println(")");
            
            // Send timeout update to Wio Terminal
            sendDataToWioTerminal();
        }

        // Print periodic status summary
        if (millis() - lastHeartbeat > 60000) // Every 60 seconds
        {
            print_status_summary();
            lastHeartbeat = millis();
        }
    }
    else
    {
        Serial.println("❌ LoRa module not available - check connections");
        sendDataToWioTerminal(); // Update Wio Terminal with disconnected status
        delay(5000);
    }
    
    delay(100); // Small delay to prevent overwhelming I2C
}

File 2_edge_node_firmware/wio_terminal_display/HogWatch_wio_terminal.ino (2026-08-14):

#include "TFT_eSPI.h"
#include <Wire.h>

TFT_eSPI tft = TFT_eSPI();

// I2C Configuration
#define I2C_SLAVE_ADDR 0x42

// Detection data structure (must match ESP32 side)
struct DetectionData {
    uint8_t fieldClear;        // 1 = clear, 0 = boar detected
    uint8_t totalDetections;   // Total detections count
    int8_t rssi;              // RSSI value
    int8_t snr;               // SNR value
    uint8_t commFailures;     // Communication failure count
    uint32_t lastDetectionTime; // Time since last detection (seconds)
    uint32_t systemUptime;    // System uptime (seconds)
    uint8_t loraConnected;    // 1 = connected, 0 = disconnected
};

// Display state
DetectionData currentData;
unsigned long lastI2CUpdate = 0;
unsigned long lastDisplayUpdate = 0;
bool dataReceived = false;
bool blinkState = false;

// Colors
#define COLOR_SAFE     0x07E0   // Green
#define COLOR_DANGER   0xF800   // Red
#define COLOR_WARNING  0xFFE0   // Yellow
#define COLOR_BG       0x0000   // Black
#define COLOR_TEXT     0xFFFF   // White
#define COLOR_GRAY     0x8410   // Gray
#define COLOR_BLUE     0x001F   // Blue

// Screen dimensions
#define SCREEN_WIDTH  320
#define SCREEN_HEIGHT 240

void setup() {
    Serial.begin(115200);
    
    // Initialize I2C as slave
    Wire.begin(I2C_SLAVE_ADDR);
    Wire.onReceive(receiveEvent);
    
    // Initialize display
    tft.init();
    tft.setRotation(3);
    tft.fillScreen(COLOR_BG);
    
    // Initialize data structure with defaults
    memset(&currentData, 0, sizeof(DetectionData));
    currentData.fieldClear = 1; // Start with field clear
    
    drawInterface();
    
    Serial.println("Wio Terminal Wild Boar Display System Started");
    Serial.print("I2C Slave Address: 0x");
    Serial.println(I2C_SLAVE_ADDR, HEX);
}

void loop() {
    unsigned long currentTime = millis();
    
    // Update display every 500ms
    if (currentTime - lastDisplayUpdate > 500) {
        updateDisplay();
        lastDisplayUpdate = currentTime;
        blinkState = !blinkState; // Toggle blink state
    }
    
    // Check for I2C communication timeout
    if (dataReceived && (currentTime - lastI2CUpdate > 10000)) {
        // No data received for 10 seconds - show communication error
        Serial.println("I2C communication timeout!");
    }
    
    delay(50);
}

void receiveEvent(int bytes) {
    if (bytes == sizeof(DetectionData)) {
        Wire.readBytes((uint8_t*)&currentData, sizeof(DetectionData));
        lastI2CUpdate = millis();
        dataReceived = true;
        
        Serial.println("--- I2C Data Received ---");
        Serial.print("Field Status: ");
        Serial.println(currentData.fieldClear ? "CLEAR" : "BOAR DETECTED");
        Serial.print("Total Detections: ");
        Serial.println(currentData.totalDetections);
        Serial.print("RSSI: ");
        Serial.print(currentData.rssi);
        Serial.println(" dBm");
        Serial.print("SNR: ");
        Serial.print(currentData.snr);
        Serial.println(" dB");
        Serial.print("Comm Failures: ");
        Serial.println(currentData.commFailures);
        Serial.print("LoRa Connected: ");
        Serial.println(currentData.loraConnected ? "YES" : "NO");
        Serial.println("------------------------");
    } else {
        Serial.print("Invalid I2C data size received: ");
        Serial.println(bytes);
        // Clear buffer
        while (Wire.available()) {
            Wire.read();
        }
    }
}

void drawInterface() {
    tft.fillScreen(COLOR_BG);
    
    // Title
    tft.setTextColor(COLOR_TEXT);
    tft.setTextSize(2);
    tft.drawString("WILD BOAR DETECTION", 20, 10);
    
    // Draw border
    tft.drawRect(5, 5, SCREEN_WIDTH-10, SCREEN_HEIGHT-10, COLOR_GRAY);
    
    // Status area background
    tft.fillRoundRect(15, 40, SCREEN_WIDTH-30, 80, 10, COLOR_GRAY);
}

void updateDisplay() {
    // Clear status area
    tft.fillRoundRect(16, 41, SCREEN_WIDTH-32, 78, 9, COLOR_BG);
    
    // Check if we have valid data
    if (!dataReceived) {
        // Waiting for data
        tft.fillRoundRect(16, 41, SCREEN_WIDTH-32, 78, 9, COLOR_GRAY);
        tft.setTextColor(COLOR_TEXT);
        tft.setTextSize(2);
        tft.drawString("WAITING FOR DATA...", 40, 70);
        return;
    }
    
    // Check I2C communication status
    bool i2cTimeout = (millis() - lastI2CUpdate > 10000);
    
    if (i2cTimeout) {
        // Communication error
        tft.fillRoundRect(16, 41, SCREEN_WIDTH-32, 78, 9, COLOR_WARNING);
        tft.setTextColor(COLOR_BG);
        tft.setTextSize(2);
        tft.drawString("COMM ERROR!", 70, 70);
        drawConnectionStatus(false, false);
        return;
    }
    
    // Main status display
    if (currentData.fieldClear) {
        // Field is safe
        tft.fillRoundRect(16, 41, SCREEN_WIDTH-32, 78, 9, COLOR_SAFE);
        tft.setTextColor(COLOR_BG);
        tft.setTextSize(3);
        tft.drawString("FIELD CLEAR", 50, 60);
        
        // Draw safe icon (checkmark)
        drawCheckmark(250, 65, COLOR_BG);
        
    } else {
        // Wild boar detected
        uint16_t bgColor = (blinkState) ? COLOR_DANGER : COLOR_WARNING;
        tft.fillRoundRect(16, 41, SCREEN_WIDTH-32, 78, 9, bgColor);
        tft.setTextColor(COLOR_TEXT);
        tft.setTextSize(3);
        tft.drawString("BOAR DETECTED!", 30, 60);
        
        // Draw warning icon
        drawWarningIcon(250, 65, COLOR_TEXT);
    }
    
    // Information panel
    drawInfoPanel();
    
    // Connection status
    drawConnectionStatus(currentData.loraConnected, true);
}

void drawInfoPanel() {
    // Info background
    tft.fillRoundRect(15, 130, SCREEN_WIDTH-30, 85, 5, COLOR_GRAY);
    
    tft.setTextColor(COLOR_TEXT);
    tft.setTextSize(1);
    
    // System uptime
    String uptimeStr = "Uptime: " + formatTime(currentData.systemUptime);
    tft.drawString(uptimeStr, 25, 140);
    
    // Total detections
    String countStr = "Total Detections: " + String(currentData.totalDetections);
    tft.drawString(countStr, 25, 155);
    
    // Last detection time
    if (currentData.lastDetectionTime > 0) {
        String lastStr = "Last Detection: " + formatTime(currentData.lastDetectionTime) + " ago";
        tft.drawString(lastStr, 25, 170);
    } else {
        tft.drawString("Last Detection: None", 25, 170);
    }
    
    // Signal quality
    String signalStr = "Signal: RSSI=" + String(currentData.rssi) + "dBm, SNR=" + String(currentData.snr) + "dB";
    tft.drawString(signalStr, 25, 185);
    
    // Communication failures
    if (currentData.commFailures > 0) {
        String failStr = "Comm Failures: " + String(currentData.commFailures);
        tft.drawString(failStr, 25, 200);
    } else {
        tft.drawString("Communication: OK", 25, 200);
    }
}
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

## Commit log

2026-08-14 Add wiring diagrams to README
2026-08-14 Update field node diagram to include analog ultrasonic circuit image
2026-08-14 Update field node diagram to use detterent-circuit.png
2026-08-14 Reorganise repository into structured layout per spec
    [HogWatch_Case_v2.stl, vela_compilation_summary.csv]
2026-08-14 Restructure ML pipeline into 3 model tiers, add photos, rename artifacts to match spec
    [epoch_100_int8_summary_Ethos_U55_High_End_Embedded.csv]
2026-08-14 Update Project Overview to explain 35kHz ultrasonic deterrence and remove contest phrase
2026-08-14 Update enclosure description to mention top slit for sliding lid
2026-08-14 Fix all README gaps: add Functionality/Output, why it should win, all diagrams, Arduino libs, Arm64 validation
2026-08-14 Replace ASCII flowchart with styled Mermaid diagram

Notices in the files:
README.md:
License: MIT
